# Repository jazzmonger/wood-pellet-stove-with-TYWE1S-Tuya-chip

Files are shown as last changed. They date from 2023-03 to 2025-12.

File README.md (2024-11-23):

Wood Pellet Stove with Tuya TYWE1S chip flashed with ESPHome gives you COMPLETE local control over ALL stove functions (and adds some).

The Discussions section also has LOTs of info: https://github.com/jazzmonger/wood-stove-with-TYWE1S-Tuya-chip/discussions
Including the discussion of a new circuit board design.



This project dives deep into the TuyaMCU parts of ESPHome that can be used to control various Tuya cloud based pellet stoves.  While the ESPHome TuyaMCU implementation is mostly robust, getting information on what it does and how it does it and why has been challenging to say the least.  I hope this helps someone else. I now have two of these stoves running ESPHome and FINALLY they function the way I want them to, not how some idiotic low-budget coder tried to program them.  I used to wake up cursing my pellet stoves.  Now I just wake up all warm and fuzzy.

The Advanced version completely replaces the Tuya Wifi module with an ESP32 D1 Mini chip and adds a whole new world of control to these stoves.

TuyaMCU Docs: https://esphome.io/components/tuya.html

The Tuya TYWE1S chips and those like it are basically just repackaged ESP8266 modules.  All the functions of the 8266 are all there.  The TuyaMCU libray in ESPHome provides an abstraction layer between the display/control module and Home Assistant. It allows control messages to be both Sent and Received from the device the module is controlling. In this case, our stove's main brain/control unit, or MCU as its called.

I'm an electronic engineer/designer by education and training, not a professional programmer, but thankfully ESPHome makes all this pretty easy. That said, I LOVE hacking this stuff, so  start with replacing the buggy, error prone Tuya control software by flashing ESPHome onto the display's TYE1S Tuya communications & controller chip.

**Product Models:** 
Cleveland Ironworks Wood Pellet Stove (there are 4 models, all use the same controller).  
https://www.cleveland-ironworks.com/products/pellet-stoves.html
I have a test bench set up with a spare control board. i have 2 models of this stove which both fail, but for different reasons.

It also appears from the Wifi module (N12210) that this exact same controller is used in Nemaxx Pellet Stove Pellet Heater P6 P9 P12.  https://www.ebay.com/itm/193755684864

Masterforge has the exact same models of this stove, all will use the same controller.

There are several others sold by Lowes, and other retailers that use the same display control board and TYWE1S chip.

There are a few displays that look slightly different but I believe all have the same basic internals. The displays have exactly the same function, just dufferent color faceplates. if they look like any of these then youre in luck!
All will have a TYWE1S chip that provide wifi functions that can be reprogrammed with ESPHome.

UPDATE: if the chip is the blue D1 Mini on the daughterboard, and the app you use is "Fire@home" and you got the stove in the EU, the stove uses the Blynk protocol, not Tuya.  We've exhausted all options trying to get this working. see the discussions. I would need the actual display board from this stove to decode the protocol being used

591DD0B1-FA41-4E61-9443-4FD6ECA933A9



The wood stoves work ok some of the time, but the stove malfunctions fairly frequently.  
Common mafunctions include:
- randomly turning off w/ the msg "Goodbye!" on the display.
- pellets failing to light in the hopper
- not coming back on after power failure
- various cryptic E messages from time to time. E1,E2,ESC1, ESO1,ESC2,ESO2,etc  
- the stove will overheat when set to ECO2 and P1, throwing ESC1 errors. mitigate this with a fan behind the stove, triggered by exhaust temp.  set combustion fan to -10 for P1 in stove settings. 
Putting a fan behind the stove also fixes E6 error code indicating the temp sensor below the pellet hopper is reading too high

**Basic Problem Definition**
Pellet stoves made by Cleveland Ironworks all use the TuyaMCU chip TYWE1S to communicate with the stove's MCU inside the display unit.  Their shoddy programmer defined multiple datapoints for the same attribute in at least 2 cases, the most important being temperature.  This results in the Tuya integration reporting a random (usually negative) false value for current temp. The other problem is it sends its temp values as degrees F and ALL esphome climate entities originate in C.  If you set your HA instance to imperial, it will automagically convert C to F.  In this case it convering what it thinks is C ( but is really F) into F again.  temp readings are whacked and there was nothing you can do until now.

link to product manual https://www.cleveland-ironworks.com/mwdownloads/download/link/id/2763

Their app is a vendor written Tuya based app that looks like this:



Simply flashing esphome to the chip gives incorrect temp readings due to the stove using F instead of C for values. a fix for this is coming (update: its fixed).  The stove below might work great in purgatory (which, Im sure, is where these stoves were built), but not in the real world...



also, the main problem with trying to control the stove by brute force by manually controlling everything in ESPHome is setting your target temp doesn't work bc it fights with the stove's internal "set temp" that is set thru the front panel. when the room temp sensor reaches the user set value it shuts off to stove - its all a self contained system. The daughterbiard w/ the TYWE1S is only there to provide wifi support.  There there is no way to convert the stove control fully to to ESPHome. too many sensors, blowers, igniters, relays and safety issues to etc to deal with. This is all best left to the dusplay and main MCU control board. But we can secretly (and safely) intervene...

**Solution**
- Flash ESPHome to the TWYE1S daughterbiard chip using TuyaMCU. This is the module that normally relays info to and from the stoves control board and also provides a WiFi control interface to the Tuya iOT China based cloud platform. ESPHome eliiminates China from the equation and gives you local, Home Assistant control.
- use the new mod I got one of the ESPhome devs to make for me and you're golden.  its defined in the esphome config file.
- if your stove is turning off for no reason w/ "Goodbye" displayed on the screen, then the automations I've provided should help mitigate this
- go a step further and make a few *very* simple mods to the display and control board and you get FULL control over this stove WITHOUT sacraficing any of the safety features built into this stove.

See the Discussions for specific solutions to some of the errors and problems I've solved over the past year of doing battle with this stove. Its in the Discussions where I show the deep mods that are available and really make this Pellet Stove shine.

Post a message in the Discussions for basic questions or create a PR (problem report) if you are doing mods to your stove and run into issues.  I've tried to be as complete as possible and probably seen every problem these stoves have and then some.
Have fun!

**Data Points used by TuyaMCU and Tuya cloud:**
```
1 - Power on (Heat)
4 - Mode P1/P2/P3P4
101 - ECO1/ECO2
104 - Error Code
105 - random, unused
106 - Set desired room Temp
107 - Current Temp
108 - Pipe Temp
109 - Protect Temp
```
Error code is dp 104 (these come back from the server as numbers and are then mapped to error codes in the vendor app).  See my sensors.yaml file for how to decode them.

*Flashing the chip*
Carefully remove it from the display module.  It unplugs easily. or leave it in the display and use the power from the display to power the chip.  Ive done it both ways, either is fine.


2A18441F-1FBA-4847-B41D-B65DCFCA9A34

this link shows you how to do it: https://tasmota.github.io/docs/TuyaMCU-Devices/#costco-charging-essentials

EDIT: for future reference, if unplugging the module from the display, I used 3.3v from the FTTD adapter to power the TYWE1S, U0TX (goes to RX on the FTTD adapter)  and U0RX (goes to TX on the FTTD adapter) then I only grounded GPIO0 at bootup to flash the chip.  Remove this ground from GPIO0 after its flashed and restart the chip. Also, connect 3.3V (not 5v) to the 3V3 pin on the TYWE1S chip, pin 4, or just leave the module plugged in and use the stove to power the chip.

WARNING - be careful when you solder wires to the board/chip to flash the chip.  I used breadbord wires w/pins and my VCC connection broke at some point and it took most of the circuit board trace off both the board AND the chip.  I salvaged it with a Frankenstein jumper, but you've been warned! Just be careful when handlin, use long wires and you should be fine.



2214C401-0F23-4C0E-A11A-6B35EF960212

The spiffy new entity with options to change Power and ECO mode. See the file uploads for all the code to generate these.

Special cards used frim HACS
type: custom:slider-entity-row
type: custom:plotly-graph

FD170D9C-2115-40DC-B2CB-CFCBC79D0ED4

My "Ultimate" Pellet Stove Command Module after completely replacing the wifi module and Tuya chip with an ESP32 D1 mini. Yes, it can be done.

Another piece of the puzzle was to snoop on the RX UART line going from the display to the MCU control board.  this lets you echo messages from the display to home assistant as there is no other way to do it. its a little flakey at times (its just display messages), but mostly works. See the discussions section on how i achieved this bit of UART magic!

    



And finally, while i have had the stove burn for 2-3 days straight, it does go out if the ultra-low burn pot settings arent just right.  So, in the "Ultimate vesion" I add a wire to monitor the UART messages from the main MCU that contain temp updates so I can measure realtime temp updates (instead of at 1 min intervals via the Tuya crap). This helps to better control the burn pot and keep the fire from going out when on "Ultra Low" setting. Again, see Discussions for more info.



Build and use at your own risk!

I will not be responsible for any damages including but not limited to: errors or omissions, loss of life, or property damage. You have been warned.

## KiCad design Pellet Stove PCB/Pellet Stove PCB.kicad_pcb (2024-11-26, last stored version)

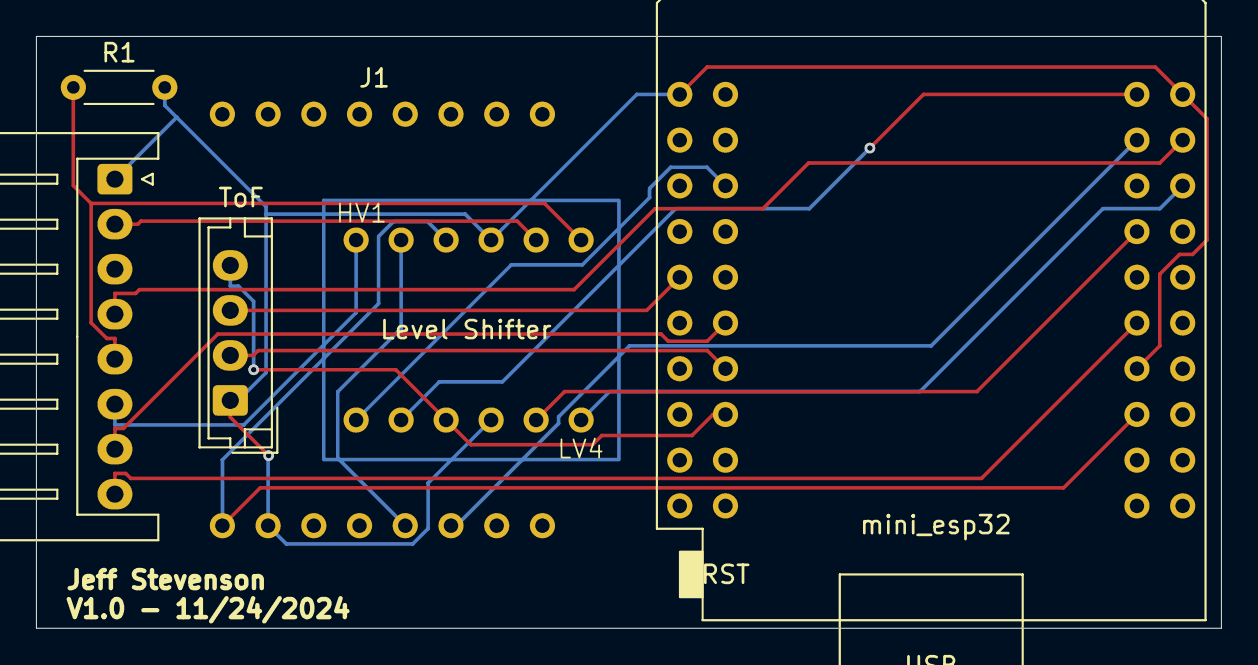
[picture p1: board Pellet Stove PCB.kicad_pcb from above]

Board: 2 copper layers, 65.8 x 32.9 mm, 6 parts (0 on the bottom side), 17 nets.

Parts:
J1: Pellet Stove Header pins
J2: Logic Level Converter
J4: MCU USB & display; JST_XH_S8B-XH-A_1x08_P2.50mm_Horizontal
J6: ToF; JST_EH_B4B-EH-A_1x04_P2.50mm_Vertical
R1: 1k; R_Axial_DIN0204_L3.6mm_D1.6mm_P5.08mm_Horizontal
U1: mini_esp32; ESP32_mini

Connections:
GND: J1.10, J2.4 (GND), J2.9 (GND), J4.1, J6.1, R1.2, U1.1 (GND), U1.22 (GND), U1.33 (GND)
unnamed: J2.3 (3.3v), J6.4, U1.16 (3V3)
unnamed: J2.12 (HV1), J4.6
unnamed: J1.13, J2.11 (HV2)
unnamed: J2.8 (HV3), J4.2
unnamed: J2.7 (HV4), J4.5, R1.1
unnamed: J1.9, J2.10 (HV), U1.35 (VCC_(USB))
unnamed: J2.1 (LV1), U1.6 (IO_26/D0)
unnamed: J2.2 (LV2), U1.21 (TXD)
unnamed: J2.5 (LV3), U1.27 (IO_21/D2/SDA)
unnamed: J2.6 (LV4), U1.26 (IO_25)
unnamed: J4.4, U1.24 (IO_27)
unnamed: J4.7, U1.12 (IO_23/D7)
unnamed: J4.8, U1.31 (IO_16/D4)
unnamed: J6.2, U1.14 (IO_05/D8)
unnamed: J6.3, U1.9 (IO_33)
unnamed: J1.14, U1.23 (RXD)

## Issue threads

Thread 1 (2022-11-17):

Goodbye! Is displayed on screen

jazzmonger, 2022-11-17:
Stove randomly turns off and displays this msg.

I've only caught it once doing this when I was standing over it. I witnessed the following:

it was operating normally, then turned off. It started the cooing down phase.
Pipe temp was over 300 and dropped down to 100. As it hit 100, the msg went from cooling down to "Goodbye!" All sensor values at that time:
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

I have an automation that looks for this condition and turns it back on. I check several conditions before turning it back on.  If we go on vacation, I'll have to turn the stoves power off as this automation will keep turning it on unless it's disabled.

alias: House  wood stove FIX Goodbye error
description: ""
trigger:
  - platform: state
    entity_id:
      - binary_sensor.bs_stove_error
    to: "on"
    enabled: true
    for:
      hours: 0
      minutes: 2
      seconds: 0
  - platform: template
    value_template: |-
      {{ states('sensor.esph_house_stove_current_temp')|float(0) +5 <=
        states('sensor.esph_house_stove_set_temp')|float(0) }}
    enabled: false
  - platform: numeric_state
    entity_id: sensor.esph_house_stove_pipe_temp
    below: 101
condition:
  - condition: state
    entity_id: climate.house_wood_pellet_stove
    attribute: hvac_action
    state: "off"
  - condition: state
    entity_id: climate.house_wood_pellet_stove
    attribute: hvac_action
    state: idle
    enabled: false
  - condition: numeric_state
    entity_id: sensor.esph_house_stove_pipe_temp
    below: 101
  - condition: numeric_state
    entity_id: sensor.esph_house_stove_set_temp
    above: 65
action:
  - service: climate.set_hvac_mode
    data:
      hvac_mode: heat
    target:
      entity_id: climate.house_wood_pellet_stove
  - service: notify.mobile_app_jeffs_128gb_ipad
    data:
      message: >-
        Stove Error. House Temp={{
        states('sensor.esph_house_stove_current_temp')}}. Set
        temp={{states('sensor.esph_house_stove_set_temp')}}
  - service: notify.mobile_app_jeffs_iphone_se
    data:
      message: >-
        Stove Error. House Temp={{
        states('sensor.esph_house_stove_current_temp')}}. Set
        temp={{states('esph_house_stove_set_temp')}}
  - service: logbook.log
    data:
      name: Stove error
      message: >-
        .  Current temp ={{ states('sensor.esph_house_stove_current_temp')}}F.
        - set temp={{states('sensor.esph_house_stove_set_temp')|float(0) }}
mode: single

jazzmonger, 2022-11-18:
New binary sensor that goes true when it detects the stove has randomly turned itself off

      bs_stove_error:
        friendly_name: "BS Stove Error"
        value_template: >-
          {{ float( states('sensor.stove_current_temp_sensor_smoothed') , 0)
          <=  float( states('sensor.esph_house_stove_set_temp') , 0)-4 and
          is_state('climate.house_wood_pellet_stove', 'off') }}

And the filtered temp which smoothed the sensors erratic behavior

  - platform: filter
    name: "esph Stove temp sensor smoothed"
    entity_id: sensor.esph_house_stove_current_temp
    unique_id: stss
    filters:
      - filter: outlier
        window_size: 4
        radius: 4.0
      - filter: lowpass
        time_constant: 100
        precision: 1

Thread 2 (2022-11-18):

[Question] Enumerating DPIDs from the Tyua MCU

jwaz73, 2022-11-18:
First of all, thank you for taking the time to document your efforts on this issue!  This is very beneficial.

A question for you.  How did you enumerate the DPIDs and Power Mode / ECO Mode maps you have in the ESPHome yaml file?

The only way I have been able to see DPID data is through the LocalTuya integration in HA.  I have looked and looked for the integer IDs in the Tuya IoT console but can only find the text representation.  I have not found anything that shows me the 'actual' value of the power or eco mode settings.  P1 = 0 for example...

I'm working with a Master Forge H140XL and the controller looks very similar to the photos you posted. Only difference seems to be the enclosure (mine is built-in to the side of the stove).

I am seeing an additional DPID from what you have documented.

105 (Value: F)

I'm thinking this is an indicator of the temperature measurement unit (Fahrenheit)...

Thanks again for sharing your hard-learned knowledge on these pellet stove controllers!

-James

jazzmonger, 2022-11-18:
You stove is the exact same one I have in my shop.  It has the same controller. Just a rebrand if a Chinese stove.  In fact, Masterforge has the same stove I have in my house as well.
Check it out
https://www.cleveland-ironworks.com/products/pellet-stoves.html

jwaz73, 2022-11-18:
I did have the 'unexpected shutdown' issue a couple of times.  Both times my display has shown me an E6 error code indicating the temp sensor below the pellet hopper is reading too high.  The stove was on P1 mode for both of these.  We do suffer regular power blinks here and each time the stove restarts from a power failure it defaults to the P1 mode.  Now that I have a path to better integration with HA I will address the power setting with automation.  I haven't flashed it yet.  It's the only heat source for my workshop so I'm waiting on a second display panel to arrive from the manufacturer before modifying.

jazzmonger, 2022-11-19:
If you adjust the combustion blower to -20 on P1 thru the menu setting, and that can also help eliminate that problem.  I run your stove also in my shop and set it on ECO2.  It heats on PI then adjusts down to P4 and back to P1 when it needs to.

the worst part about the errors is they don't clear.  At first I thought you had to power cycle the whole stove to clear them,  but I recently figured out (by reading the manual for the Nemaxx stove - its VERY detailed)  that if you press and hold thumbs up, it will also clear the error.  But unfortunately, there is no way I've found (yet) to clear an error condition programatically.  it might be possible to take an unused GPIO pin off of the TYWE1S and wire it into the thumbs up button, but for now I just use a wifi outlet and power cycle that.

The good news is the TYWE1S module can either be installed, or not.  Its just a daughterboard to the main MCU.  It just relays msgs to and from the main MCU.  In fact, my vendor sent me 2 displays w/out the wifi modules by mistake.

One of my "down time" projects I'm contemplating is wiring into the display to see what it's doing at all times.  I just ordered a 16ch logic probe from China for like $60.  Tons of sw for them too.

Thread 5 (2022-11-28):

Control board and mods

jazzmonger, 2022-11-28:
The control board has several opto  isolator Ics that control triacs that control all the ac motors and igniter.  The triacs are 136SE6 which are rated for 4A, so at 120v they can sink 480watts.

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

These triacs are controlled by the opto isolator's pin 2.  They turn ON when pin2 goes from 1/ON to ground/0.

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

igniters:
The std igniter is 300w, so most common igniters up to 400w should work, drawing 3.2A from the triac, leaving a 15% margin of the 4A max triac current capacity.  These stoves have 6" x 3/8" 300w igniters held in place by 2 Phillips head screws.  Mine failed a week ago and it takes a couple weeks to get these so I ordered some extra ones to have on hand for the next failure.

ECO2 mode starts at P1 and when temp is reached throttles down to P4. In a large area like my shop, this works well.  The stove burns continuously at P4 unless it gets colder than set temp-3 degrees then switches back to P1 until current temp=settemp+1. And the cycle repeats.

For smaller areas, P4 is too hot and the room gets overheated without the stove turning off. Now that I know how to control the triac for the auger, my plan is to echo the signal from the MCU auger pin unless I choose a new level P5 that I will define in the Power select, and that will lengthen the off time of the auger. I'll leave the on time the same so pellets don't get stuck.

Wind fan
This fan is controlled by the triac I labeled "w" and goes from 107vac on P1 to 97v on P4 thus varying the speed of the hopper fan.I hooked a std box fan to this output to figure this out. The "S" setting in the menu controlling the various P levels is what controls this triac.

jazzmonger, 2022-12-05:
After about 6 weeks, I finally got my logic Analyzer from China!  Sheesh, I'm an EE and it took me this long to finally get a logic analyzer.  I put it to good use yesterday and monitored all of the opto-isolators as the stove goes through its cycles.

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

Here are the definitive auger on/off times I measured on the Logic Analyzer for each of the Power Levels P1-P4

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

Hopefully, I'll use this info to add a new P5 program that really slows down the burn, but allows me to use ECO2 and keep the stove burning instead of turning it off and turning it back on.

My plan is to echo the auger info until I want the new P5 plan, and then I'll play w/ the value until I get the burn I want.  Time will tell!

jazzmonger, 2022-12-12:
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

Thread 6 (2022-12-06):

Things that made this project easier

jazzmonger, 2022-12-06:
How do I make notifications in iOS persistent?
Settings.
Apps and Notifications.
App Info.
App notifications.
Toggle off the On option.

Logic Analyzer $22
https://m.aliexpress.us/item/2251832380622770.html

igniters $18
These stoves use a 7" igniter that glows only at the tip.  I haven't found an exact replacement yet But this works for now:
https://www.amazon.com/dp/B083C56W4G?psc=1&ref=ppx_yo2ov_dt_b_product_details
I had to use a cutoff wheel to carefully remove the threads so it could push all the way into the burn pot,  not ideal but better than manually lighting with a propane torch.

more to come...

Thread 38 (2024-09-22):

Maybe only 2 UARTS are needed

Geo-Ron, 2024-09-22:
In your code in ESP32 Pellet Stove wit mods.yaml I noticed you have 2 UARTS defined.

- One for reading the TX pin of the interconnect between display and main MCU
- One for reading the RX ping of the interconnect.

Since the UART debugging can be done in BOTH directions (as specified in [ESPHOME UARTS Debugging](https://esphome.io/components/uart.html#debugging), I propose the following code(change) to combine 2 UART definitions into only one:

```yaml
#
# define 2 hardware UARTS, 1 for TuyaMCU, other for MCU Display & temps monitoring
#
uart:
#communication from TuyaMCU to tywe1s chip UART1
  - id: tywe1s_uart
    rx_pin: RX # Receives data from MCU, RX label on ESP32
    tx_pin: TX # Transmits data to MCU, TX label on ESP32
    baud_rate: 9600
#Display message decoding UART2
  - id: mcu_uart_comms
    tx_pin: GPIO16 #attach new wire to TX labled pin on DISPLAY board
    rx_pin: GPIO21 #attach new wire to RX labled pin on DISPLAY board
    baud_rate: 2400
    rx_buffer_size: 80
    debug:
      direction: BOTH #this is the MAIN change
      dummy_receiver: true ## maybe this can be returned to false???
      after:
        delimiter: [0xCC, 0x33]
      sequence:
        - lambda: |-
            UARTDebug::log_hex(direction, bytes, ' ');     
            //Still log the data
            //Some packets have 5 bytes
            //might have to make this 3 if delimitar bytes get removed....

            if (bytes.size()==5) {
                if(bytes[0]==0xAA && bytes[1]==0x00) {
                if(bytes[2]==0x20)
                  id(MCUrawString).publish_state("Welcome to use");
                if(bytes[2]==0x6A)
                  id(MCUrawString).publish_state("Goodbye!");      
                if(bytes[2]==0x69)
                  id(MCUrawString).publish_state("Cleaning");
                if(bytes[2]==0x63)
                  id(MCUrawString).publish_state("Cleaning");
                if(bytes[2]==0x65)
                  id(MCUrawString).publish_state("Lighting");
                if(bytes[2]==0x66)
                  id(MCUrawString).publish_state("Stabilization");
                if(bytes[2]==0x62)
                  id(MCUrawString).publish_state("Switching OFF");
                //if(bytes[2]==0x??)
                  //id(MCUrawString).publish_state("Cooling");                         
              }      
            }
            //Some packets have 6 bytes
            if (bytes.size()==6) {
              if(bytes[1]==0x01 && bytes[2]==0x46 && bytes[3]==0x02)
                id(MCUrawString).publish_state("Welcome to use");
                //AA:00:59:CC:33
              if(bytes[1]==0x01 && bytes[2]==0x46 && bytes[3]==0x02)
                id(MCUrawString).publish_state("Switching off");         
              if(bytes[1]==0x01 && bytes[2]==0x49 && bytes[3]==0x80)
                id(MCUrawString).publish_state("Stabilization");
              if(bytes[1]==0x01 && bytes[2]==0x49 && bytes[3]==0x00)
                id(MCUrawString).publish_state("Stabilization");
              if(bytes[1]==0x01 && bytes[2]==0x49 && bytes[3]==0x81)
                id(MCUrawString).publish_state("ECO2");
              if(bytes[1]==0x01 && bytes[2]==0x48 && bytes[3]==0x80)
                id(MCUrawString).publish_state("ECO1");
              if(bytes[1]==0x01 && bytes[2]==0x48 && bytes[3]==0xC0)
                id(MCUrawString).publish_state("Idling - ECO2");
              if(bytes[1]==0x01 && bytes[2]==0x49 && bytes[3]==0x01)
                id(MCUrawString).publish_state("Idling - ECO2");
              if(bytes[1]==0x01 && bytes[2]==0x48 && bytes[3]==0x83)
                id(MCUrawString).publish_state("ECO1");
              if(bytes[1]==0x01 && bytes[2]==0x48 && bytes[3]==0xC3)
                id(MCUrawString).publish_state("ECO2");
              if(bytes[1]==0x01 && bytes[2]==0x49 && bytes[3]==0x81)
                id(MCUrawString).publish_state("Idling - ECO2");
            }

            //from Display control board RX pin to MCU board RX pin UART3
            //gives us real time exhaust pipe temps in middle byte
            //the full string-> the 7th HEX has the value I want(B8): AA:05:4B:00:00:26:B8:26:CC:33

            if (bytes.size()==10) {       
              // works up to approx 275 then it goes wonky somehow needing -72 instead of -36
              //but who cares, we only need stable values to stoke the fire
              id(pipe_converted).publish_state(((bytes[6]) * 1.8) - 4.0);  
            }

```

jazzmonger, 2024-09-22:
Have at it!  I was just happy I finally got everything working the way it was.  I spent countless days with the devs getting this working.  I'm sure there are many other ways to do it. If you can also get a better handle on decoding the screen messages, that will be a big improvement, especially after a recovery on reboot or power failure.

Geo-Ron, 2024-09-22:
> Have at it! I was just happy I finally got everything working the way it was. I spent countless days with the devs getting this working. I'm sure there are many other ways to do it. If you can also get a better handle on decoding the screen messages, that will be a big improvement, especially after a recovery on reboot or power failure.

Will do, if I get things wired up!

jazzmonger, 2024-09-23:
Btw, my Discord username is @jazzmonger
I lurk in HA, ESPHome & other channels
https://discord.gg/Tf3jatQa

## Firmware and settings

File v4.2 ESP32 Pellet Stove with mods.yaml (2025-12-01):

#---------------------------------------------------------
# TO DO: 
# 1) add "lighting" flag.  Don't clear it until temp hits 275F.
#  then prevent P5 until flag is cleared and stove has been properly lit.
#  this will reduce the stove flame-outs
# 2) add svariable for initial power level so different rooms can be accomodated.
#
# TUYA WOOD PELLET STOVE Converted to ESP32
# TO DO: 
#
# TUYA WOOD PELLET STOVE Converted to ESP32
# version 4.2 Nov 30 2025
# Added PID controller to iding mode that changes auger OFF time dynamically
# Start w/ these values PB = 80, Td=35 , Ti=180
#
# version; 3.1
# date 12/28/24
# Add routines to shut of Auger every time it shouldn't be on.
# date: 03-21-23 bug fixes
# version; 3.0.1
# date: 03-21-23 bug fixes
# 3.0 converted to ESP32, added realtime exhaust sensor
# 2.0 added fire stoking function
# 1.0.0 added a Power Level P5 (ultra low power) that is fully configurable while in ECO2 mode.
# 1.1.0 added echo of actual display messages and status via Display's MCU UART monitoring
#
# All of these mods give a new "Ultra Low" power level which turns down the heat during IDLE mode so the stove goes thru fewer (no)
# on/off/igniter cycles and just maintains a lower heat output (for smaller rooms)
# when the room cools enuf, ECO2 mode will kick back to "Heating" which
# turns off this new Ultra Low power level, then once the room temp is +2F above set temp, stove
# goes into "Idle" mode again and new Ultra Low is active again.  The cycle repeats and the stove stays lit.
# and room doesn't drastically heat up driving your wife nuts.
# These mods ***require*** replacing the Tuya chip with an ESP32 D1 Mini & some MCU control board and Display board mods.  
# See Github Discussions for complete details
#
# NOTE: I am NOT a career/pro programmer.  There is probably tons of opportunity to
# consolidate many of the if/then statements that check things into convoluted programmer-porn style 
# Lambda evaluations, but I hate writing and debugging Lambdas,
# so my code makes way more sense for the average person and is very easy to debug. 
# Your mileage may vary. 
# And, more inportant, it gets the job done!
#----------------------------------------
# GPIO16 <- TX PIN ON DISPLAY BOARD
# GPIO21 -> RX PIN " " "
# GPIO27 <- MCU CONTROL BOARD SENSOR FROM MCU
# GPIO25 - > AUGER OUT TO OPTOISOLATOR
# GPIO19 -> LED ON DISPLAY FOR P5
# GPIO26 -> THUMBS UP RESET  
# GPIO17 - SDA
# GPIO33 - SCL
#--------------------------------------------------------
substitutions:
  device_name: "house-wood-pellet-stove"
  device_description: House Pellet Stove running ESPHome
  friendly_name: House Wood Pellet Stove
  location: House
  lighting_count: "55" #sets max number of dumps of pellets during lighting
#----------------------------------------------------------
#
esp32:
  board: wemos_d1_mini32
  framework:
   type: arduino
#
api:
  reboot_timeout: 0s # 0s is disabled so if we lose home assistant API keep running
#
# define 3 hardware UARTS, 1 for TuyaMCU, others for MCU Display & temps monitoring
#
uart: 
#communication from TuyaMCU to tywe1s chip UART1
  - id: tywe1s_uart
    rx_pin: RX # Receives data from MCU, RX label on ESP32
    tx_pin: TX # Transmits data to MCU, TX label on ESP32
    baud_rate: 9600
#Display message decoding UART2
  - id: mcu_uart_TXpin
    rx_pin: GPIO16 #attach new wire to TX labled pin on DISPLAY board
    baud_rate: 2400
    debug:
      direction: RX
      dummy_receiver: true
      after:
        delimiter: [0xCC, 0x33]
      sequence:
        - lambda: |-
            UARTDebug::log_hex(direction, bytes, ' ');             
            //Still log the data     
            //Some packets have 5 bytes  
            //might have to make this 3 if delimitar bytes get removed....
            if (bytes.size()==5) {
                if(bytes[0]==0xAA && bytes[1]==0x00) {
                if(bytes[2]==0x20)
                  id(MCUrawString).publish_state("Welcome to use");    
                if(bytes[2]==0x6A)
                  id(MCUrawString).publish_state("Goodbye!");              
                if(bytes[2]==0x69)
                  id(MCUrawString).publish_state("Cooling");
                if(bytes[2]==0x63)
                  id(MCUrawString).publish_state("Cleaning");
                if(bytes[2]==0x65)
                  id(MCUrawString).publish_state("Lighting");
                if(bytes[2]==0x66)
                  id(MCUrawString).publish_state("Stabilization");
                if(bytes[2]==0x62)
                  id(MCUrawString).publish_state("Switching OFF");
                //if(bytes[2]==0x??) 
                  //id(MCUrawString).publish_state("Cooling");                                 
              }              
            }
            //Some packets have 6 bytes
            if (bytes.size()==6) {
              if(bytes[1]==0x01 && bytes[2]==0x46 && bytes[3]==0x02) 
                id(MCUrawString).publish_state("Welcome to use");
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

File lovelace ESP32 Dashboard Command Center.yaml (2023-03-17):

views:
  - theme: Backend-selected
    title: House
    icon: mdi:fireplace
    badges: []
    cards:
      - type: conditional
        conditions:
          - entity: binary_sensor.feeding_ok_flag
            state: 'off'
        card:
          type: markdown
          content: Cat Food Empty!!! FILL IT
          title: Cat Food Empty
      - type: vertical-stack
        cards:
          - type: markdown
            content: |

              {{states("sensor.house_display_text_sensor")}}
            card_mod:
              style: |
                ha-card {
                  font-family: 'Dotty';
                  #background: url("/local/oled2.jpg");
                  #background-size: 100% 400px;
                  background-color: CornflowerBlue;
                  font-size: 60px;
                  color: blue;
                  border: solid 1px var(--primary-color);
                  text-align: center

                  }
          - type: entities
            entities:
              - entity: climate.house_wood_pellet_stove
              - type: custom:slider-entity-row
                entity: climate.house_wood_pellet_stove
                full_row: true
                toggle: true
              - entity: select.house_power_select
              - entity: select.house_eco_select
                name: ECO1=Heat then OFF, ECO2=P1 then P4 Maintain
                show_header_toggle: false
                state_color: true
          - show_name: true
            show_icon: false
            show_state: true
            type: glance
            entities:
              - entity: sensor.house_stove_error_code
                name: Error code
              - entity: sensor.house_stove_current_temp
                name: Curr temp
              - entity: sensor.house_stove_current_temp
                name: Smoothed
              - entity: sensor.house_stove_set_temp
                name: Set temp
              - entity: sensor.house_uart_pipe_temp
                name: UART Pipe
            state_color: false
          - type: entities
            entities:
              - entity: switch.house_stove_fan_socket_1
                name: Cooling Fan @225F
                secondary_info: last-changed
              - entity: automation.house_pellet_stove_hvac_am_5_30_to_70
                name: HVAC Schedule
                secondary_info: last-changed
              - entity: sensor.house_error_code_decoded
                name: Error Msg
                secondary_info: last-changed
              - entity: sensor.house_stove_pipe_heating_or_cooling
                name: Stove Exhaust temp is currently
                state_color: true
              - entity: switch.tantan_176
              - entity: automation.fix_wood_stove_error
              - entity: automation.house_pellet_stove_turn_on_if_temp_60
              - entity: sensor.house_wifi_signal
              - entity: sensor.house_wifi_signal_db
      - type: conditional
        conditions:
          - entity: sensor.house_stove_error_code
            state_not: '0'
        card:
          type: markdown
          content: STOVE ERROR! Some Ting Wong
          title: Pellet Stove Error
      - type: conditional
        conditions:
          - entity: binary_sensor.backups_stale
            state: 'On'
        card:
          type: markdown
          content: >-
            Backups are stale! Please visit the "Home Assistant Google Drive
            Backup" add-on status page for details.
          title: Stale Backups!
      - type: vertical-stack
        cards:
          - type: custom:mini-climate
            entity: climate.bedroom_heater
            indicators:
              power:
                icon: mdi:power-plug
                source:
                  entity: switch.bedroom_heater_plug
                  values:
                    'on': heating
                    'off': idle
              power_consumption:
                icon: mdi:flash
                unit: W
                round: 1
                source:
                  entity: sensor.bedroom_heater_plug_power
            temperature:
              unit: °F
              round: 1
            hvac_mode:
              style: '(value, entity) => ({ color: ''red'' })'
              source:
                'off':
                  icon: mdi:power-plug-off-outline
                  name: 'off'
                heat:
                  icon: mdi:fire
                  name: heat
            change_action: >
              (selected, entity) => this.call_service('climate',
              'set_hvac_mode', { entity_id: entity.entity_id, hvac_mode:
              selected })
      - type: custom:plotly-graph
        defaults:
          entity:
            show_value: true
        hours_to_show: 1
        entities:
          - entity: sensor.house_stoking_sensor
            filters:
              - filter: y !== null && +y > 100
            yaxis: y1
            show_value: false
            line:
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

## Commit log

2022-12-06 Add files via upload
    Sensor.yaml file containing sensor definitions referenced in automations and Lovelace cards
2022-12-21 Add files via upload
    Modifications to add new P5 power level that modifies Auger feed rates. Requires modifying both the display board and MCU board
2022-12-23 Adds new Power Level 5. NOTE: requires mods to MCU board
    config file that adds a Power Level P5 that is fully configurable while in ECO2 mode.
    The hope is this will turn down the heat slightly so the stove goes thru fewer on/off cycles and just maintains a heat adjust so the room just cools slightly. ECO2 mode will kick back to "Heating" wh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
    Requires MCU and Display board simple mod. See discussions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
2022-12-23 adds sensors for wood pellet stove
2023-01-11 Add files via upload
    #adds a Power Level P5 that is fully configurable while in ECO2 mode.
    #adds echo of actual display messages and status via MCU UART monitoring
    #
    #These mods will turn down the heat slightly during idle mode so the stove goes thru fewer
    #on/off cycles and just maintains a lower heat setting
    #so the room just cools slightly. when room cools, ECO2 mode will kick back to "Heating" which
    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
2023-01-11 New power level P5. REQUIRES MODS!
    #turns off this new power level, then once the room temp is +2F above set temp, stove
    #goes into "Idle" mode and new P5 is active again. The cycle repeats and the stove stays lit.
    #Requires MCU and Display board simple mod. See discussions for complete details
    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
2023-01-18 Update New power level P5 wood-pellet-stove.yaml
2023-01-21 Create new power level P5. Requires mods to Display/control bd
2023-01-28 Basic Pellet Stove Lovelace card
    Use this with basic pellet stove , no physical mods.
    All Sensor names assume you use the following naming conventions in ESPHome config file:
    substitutions:
    device_name: "house-wood-pellet-stove"
    device_description: House Wood Pellet Stove running ESPHome
    friendly_name: House Wood Pellet Stove
    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
2023-01-28 Pellet Stove Sensor entries
    Add these sensors to your sensor.yaml file
2023-01-28 configuration.yaml entries for binary_sensors
    add these binary sensors to your configuration.yaml file
2023-03-17 D1 Mini ESP32 firmware replaces entire Wifi daughter board
2023-03-17 Lovelace Command Center Dashboard - ESP32 version
2023-03-17 Sensor.yaml entries for Pellet stove
2023-04-10 ESP32 chip replaces TYWE1S
    Plus this adds a TON of features
    [ESP32 Pellet Stove wit mods.yaml]
2024-11-23 Pellet Stove PC Board KiCad design files, Symbols & Footprints
    [Pellet Stove PCB.kicad_pcb, Pellet Stove PCB.kicad_sch]
2025-01-05 ESP32 Pellet Stove with mods.yaml
2025-02-17 PID Version of Ultimate contoller.
    PID Version of Ultimate contoller.
2025-02-17 PID version of Modified Pellet Stove
    Auger mod on the main board is now corolled a low temps by a PID controller.
    [ESP32 Pellet Stove wit mods - PID Version.yaml]
2025-02-17 Update ESP32 Pellet Stove wit mods - PID Version.yaml
    [ESP32 Pellet Stove wit mods - PID Version.yaml]
2025-11-15 Wood Pellet Stove Basic Config using ESP32
    Requires my pellet stove circuit board and an ESP32 to use this file
    # No mods to the pellet stove control board are required
    # Adds local sensors for all attributes previously in Tuya cloud
2025-11-15 sensor.yaml entries for home assistant
2025-11-15 ESP32 Pel. Stove with mods - PID Version.yaml
    [ESP32 Pellet Stove wit mods - PID Version.yaml]
2025-11-16 No mods with esp32 basic config & my circuit board
    Basic replacement of TYWE1S with my circuit & circuit board. No mods necessary.
    [wood-pellet-esp32-basic-config.yml]
2025-11-16 v4.1 ESP32 Pellet Stove with mods.yaml
2025-11-16 v4.1 ESP32 Pellet Stove with PID - requires mods.yaml
2025-12-01 Update v4.2 ESP32 Pellet Stove with mods.yaml
2025-12-01 Rename v4.1 ESP32 Pellet Stove with mods.yaml to v4.2 ESP32 Pellet Stove with mods.yaml
2025-12-30 Add Sensor for Exhaust and protect datapoint
2026-10-29 Fix TYWE1S basic ESPHome config: build, UART pins, serial logging
    Three regressions crept into the basic TYWE1S config through later edits:
    - df6221c moved the board back to the removed top-level `platform:`/`board:`
    syntax. ESPHome 2026.10 rejects it ("Platform missing"), so the file
    failed validation before compiling anything. Use `esp8266: board: esp01_1m`.
    - a9d41b2 changed the TuyaMCU UART from GPIO13/GPIO15 to `RX`/`TX`
    (GPIO3/GPIO1). The TYWE1S talks to the display MCU on GPIO13/GPIO15
    (original working config aedd36a; upstream discussion #31). Restore them.
    - c2971bd commented out `logger: baud_rate: 0`. TuyaMCU uses hardware
    UART0 (swapped onto GPIO13/15), so serial loggi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
2026-10-29 Add no-flash local control path: tuya-local profile, guide, LAN checker
    Owners who can't take the stove down can get local Home Assistant control
    without soldering or flashing. Keep the stock TYWE1S firmware, move the
    stove from the vendor app into Tuya Smart / Smart Life, and let tuya-local
    fetch the local key via its QR login.
    - tuya-local/pellet_stove_tywe1s.yaml: device profile (climate with P1-P4
    presets and degF units, ECO select, exhaust/protect temp sensors, DP 104
    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
2026-10-29 Document profile assumptions and swapped-RX/TX symptom
    - Units: sensors 108/109 are fixed to degF; say how to switch to C.
    - Set-temp range 50-90 F is a UI clamp guess; point at the data model.
    - Fault description decodes single faults only; stove_check decodes
    combinations.
    - Path B: repeated 'Initialization failed at init_state 0' means swap the
    RX/TX wires first (or the stove isn't TuyaMCU, as in upstream #31).
2026-10-29 Guide: stove pairs via Add Manually, not auto-scan
    Tuya Smart's auto-scan only finds Bluetooth devices and pairing hotspots,
    so the WiFi-only TYWE1S never shows up there. Document the Add Manually
    route, the 2.4 GHz network requirement, and the AP-mode fallback. Note
    that Tuya Smart accepted the OEM product key on a real stove.
